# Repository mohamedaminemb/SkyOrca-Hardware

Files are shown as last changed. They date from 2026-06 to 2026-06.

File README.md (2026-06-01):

# SkyOrca — Quadcopter Drone Hardware

<p align="center">
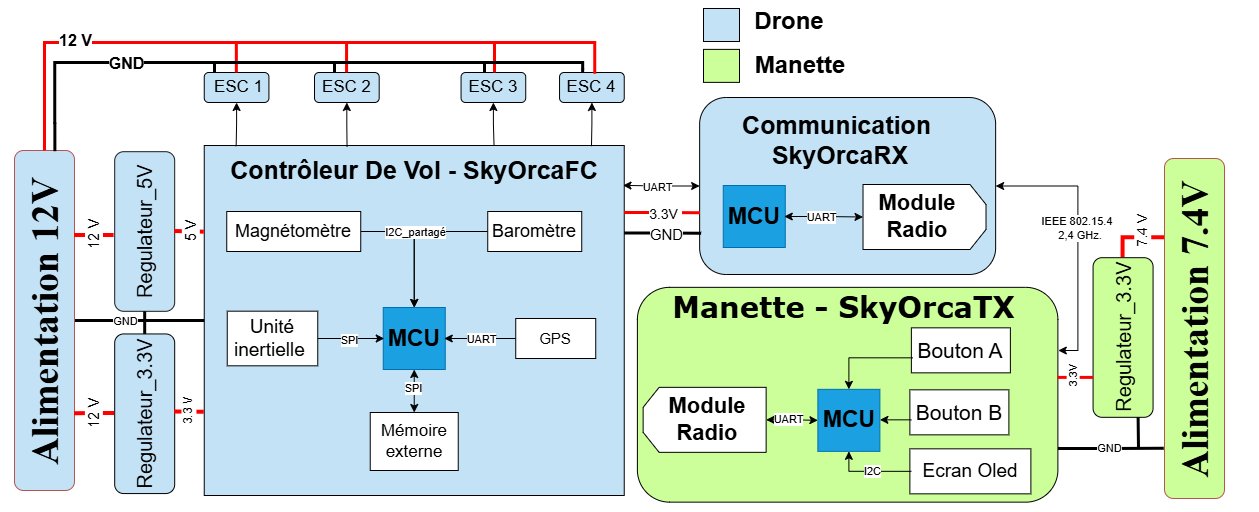
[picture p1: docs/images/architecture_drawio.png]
SkyOrca System Architecture
  
</p>

<p align="center">
  
  
  
  
  
</p>

> **SkyOrca** is a fully custom quadcopter drone system designed from scratch at ENSI (Tunisia), in partnership with [LAB619 Engineering & Consulting Services](https://lab619.tn). This repository contains the complete hardware design — schematics, PCB layouts, Gerber files, and BOMs — for all three boards.

---

## System Overview

SkyOrca is built around three custom PCBs that together form a complete drone flight & control chain:

| Board | Role | MCU | Dimensions |
|---|---|-----|---|
| **SkyOrcaFC** | Flight Controller | STM32F405RGTx @ 168 MHz | 60 × 50 mm |
| **SkyOrcaTX** | Remote Controller (Transmitter) | ATmega328P-P @ 8 MHz | 50 × 35 mm |
| **SkyOrcaRX** | Communication Module (Receiver) | ATmega2560-16A @ 8 MHz | 30 × 25 mm |

---

## Repository Structure

```
SkyOrca-Hardware/
├── hardware/
│   ├── SkyOrcaFC/              # Flight Controller Board
│   │   ├── kicad/              # KiCad project files (.kicad_pro, .kicad_sch, .kicad_pcb)
│   │   ├── gerbers/            # Production Gerber files + drill files
│   │   └── bom/                # Bill of Materials (CSV + interactive iBOM)
│   ├── SkyOrcaTX/              # Remote Controller Board
│   │   ├── kicad/
│   │   ├── gerbers/
│   │   └── bom/
│   └── SkyOrcaRX/              # Receiver Module
│       ├── kicad/
│       └── bom/
├── docs/
│   ├── images/                 # architecture_drawio.png + board renders
│   ├── SkyOrcaFC.md
│   ├── SkyOrcaTX.md
│   ├── SkyOrcaRX.md
│   └── design_decisions.md
├── .gitignore
├── LICENSE
└── README.md
```

---

## Board Details

### SkyOrcaFC — Flight Controller

The brain of the drone. Reads all sensors, runs stabilization algorithms, and drives the four ESCs.

**Key components:**
- **MCU:** STM32F405RGTx — Cortex-M4F @ 168 MHz, hardware FPU (quaternion math, sensor fusion at 400 Hz)
- **IMU:** MPU-6000 — SPI @ 20 MHz, DMA-triggered via EXTI interrupt, 400 Hz control loop
- **Barometer:** MS5611-01BA — 10 cm altitude resolution, I²C shared bus
- **Magnetometer:** HMC5883L — I²C shared bus
- **GPS:** u-blox MAX-M10S — multi-constellation (GPS/GLONASS/Galileo/BeiDou), UART
- **Flash:** W25Q128JVS — 128 Mbit, SPI @ 133 MHz, flight data logging
- **Power:** Dual TPS5430DDA buck converters (12V→5V and 12V→3.3V)
- **PCB:** 4-layer, 60×50 mm (rev 2), manufactured by JLCPCB

> **PCB revisions:** The first revision (50×50 mm) was redesigned due to GPS/DC-DC proximity and thermal density issues. See [`docs/SkyOrcaFC.md`](docs/SkyOrcaFC.md) for the full analysis.

---

### SkyOrcaTX — Remote Controller

Hand-held transmitter reading pilot inputs and displaying telemetry.

**Key components:**
- **MCU:** ATmega328P-P @ 8 MHz (DIP-28)
- **Radio:** XBee 802.15.4 module — bidirectional, up to 1.6 km range, UART interface
- **Inputs:** 2× analog joysticks (4-axis), 2 buttons
- **Display:** OLED (I²C) — battery level, altitude, RSSI
- **Power:** TPS5430DDA buck converter (7.4V→3.3V)
- **PCB:** 4-layer, 50×35 mm

---

### SkyOrcaRX — Receiver Module

On-board radio bridge between the XBee link and the Flight Controller.

**Key components:**
- **MCU:** ATmega2560-16A @ 8 MHz — 4 hardware UARTs (radio / FC link / debug / spare)
- **Radio:** XBee 802.15.4 module
- **Interface to FC:** UART2 → `IBUS_RX_MCU` on SkyOrcaFC
- **Power:** 3.3V supplied directly by SkyOrcaFC
- **PCB:** 4-layer, 30×25 mm

---

## Inter-Board Communication

| Link | Signal | Protocol |
|---|---|---|
| TX → RX (commands) | XBee RF 2.4 GHz | IEEE 802.15.4 |
| RX → FC (commands) | `UART2` → `IBUS_RX_MCU` | UART |
| FC → TX (telemetry) | `MSP_TX_MCU` → XBee → `RXD_MCU` | UART + XBee RF |
| FC → ESC 1–4 | `Signal_ESC1–4` | PWM |

All three boards share a **3.3V logic level**, eliminating any need for level shifters between STM32 and ATmega devices.

---

## Getting Started

### Prerequisites

- [KiCad 9.0.x](https://www.kicad.org/download/) to open and edit the project files

### Opening a Project

```bash
git clone https://github.com/mohamedaminemb/SkyOrca-Hardware.git
cd SkyOrca-Hardware

# Open the Flight Controller in KiCad
kicad hardware/SkyOrcaFC/kicad/flightcontrolerPCB.kicad_pro
```

### Ordering PCBs (SkyOrcaFC)

Upload `hardware/SkyOrcaFC/gerbers/gerbers_production.zip` to [JLCPCB](https://jlcpcb.com):

| Setting | Value |
|---|---|
| Layers | **4** |
| PCB thickness | **1.6 mm** |
| Surface finish | **HASL (lead-free)** or **ENIG** |
| Min trace/space | **0.15 / 0.15 mm** |

---

## Design Philosophy

This project follows a **hardware/software co-design** methodology. Every component choice is directly motivated by firmware constraints. See [`docs/design_decisions.md`](docs/design_decisions.md) for the full rationale.

---

## Project Context

SkyOrca is a design and development project (PCD) at **ENSI** (École Nationale des Sciences de l'Informatique, Tunisia), developed in the context of Tunisia's first civil drone legislation (Finance Law 2026, Article 135), in collaboration with **LAB619 Engineering & Consulting Services**.

**Team:** Mohamed Amine Embarki · Hamza Soltani  
**Supervisors:** Mme. Chadha Jerad · M. Jawher Mansour (LAB619)  
**Tools:** KiCad 9.0.4 · JLCPCB

---

## License

Hardware designs are released under the **CERN Open Hardware Licence v2 – Strongly Reciprocal (CERN-OHL-S)**.  
See [`LICENSE`](LICENSE) for details.

---

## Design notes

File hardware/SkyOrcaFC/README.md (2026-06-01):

# SkyOrcaFC — Flight Controller Board

> Full design documentation: [`docs/SkyOrcaFC.md`](../../docs/SkyOrcaFC.md)

## Quick Specs

| Parameter | Value |
|---|---|
| MCU | STM32F405RGTx |
| Dimensions | 60 × 50 mm |
| Layers | 4 |
| Power input | 12V (LiPo 3S) |
| Control loop | 400 Hz (DMA, IMU interrupt) |
| Revision | 2 (production) |

---

## 3D Views

| Front | Back |
|---|---|
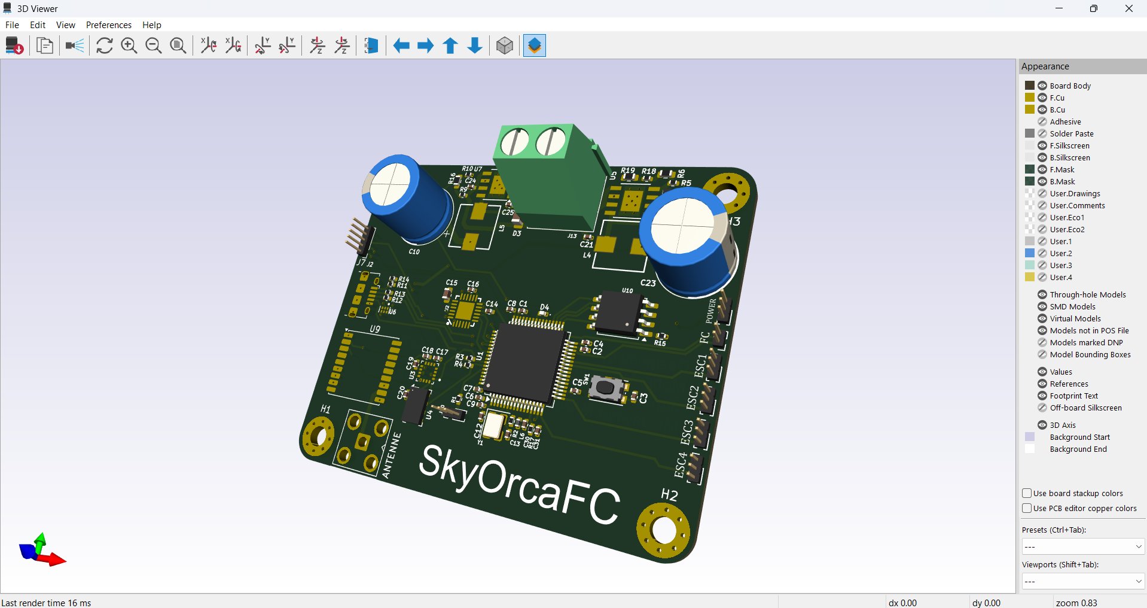
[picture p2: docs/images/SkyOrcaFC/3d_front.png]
3D Front
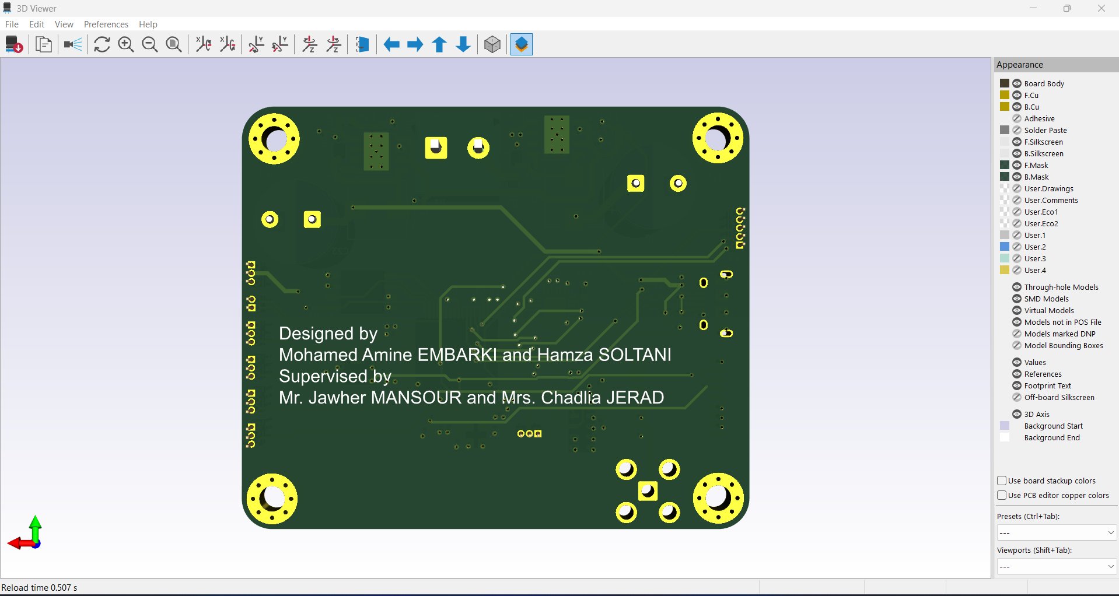
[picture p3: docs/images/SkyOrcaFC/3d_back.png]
3D Back
|  |  |

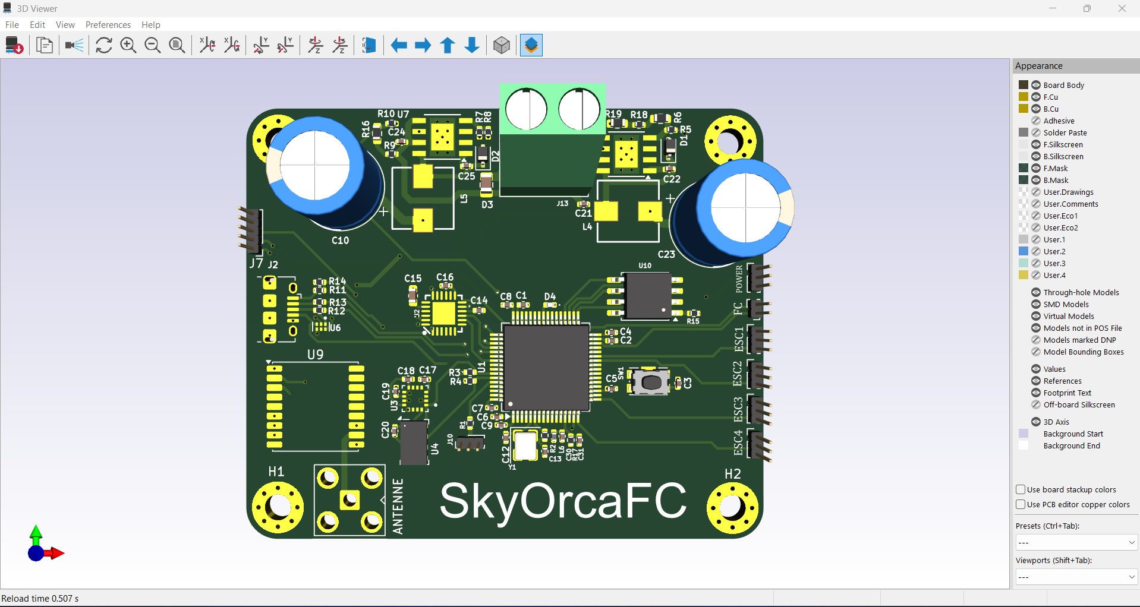
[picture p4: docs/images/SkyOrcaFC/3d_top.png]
3D Top


---

## PCB Layers

| Layer | Preview |
|---|---|
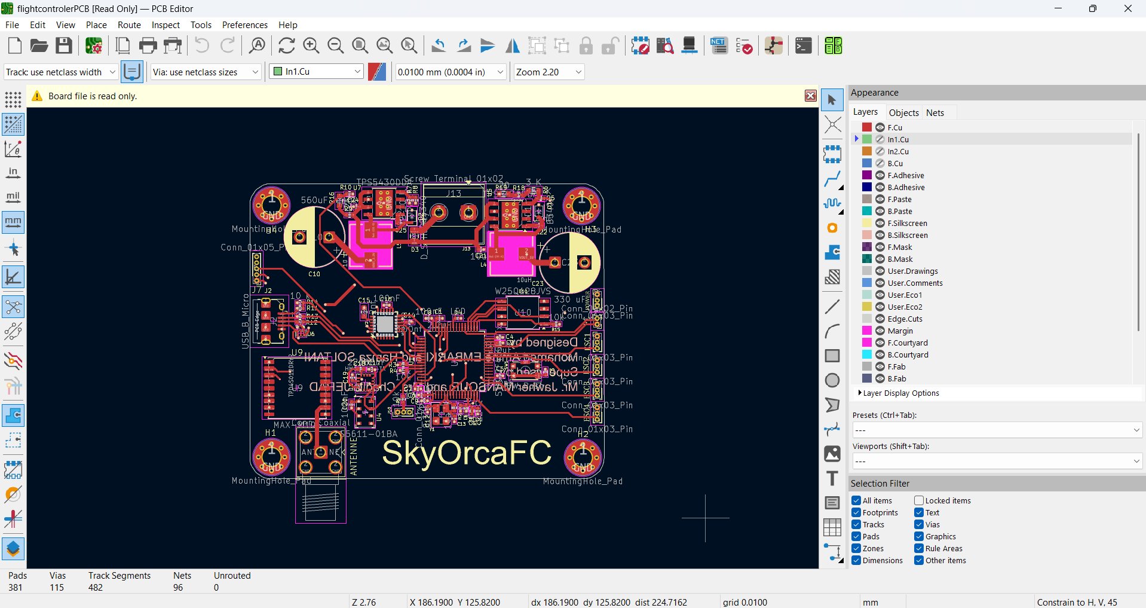
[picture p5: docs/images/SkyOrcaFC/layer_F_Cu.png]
F.Cu
| **F.Cu** — Front copper (signal + components) |  |
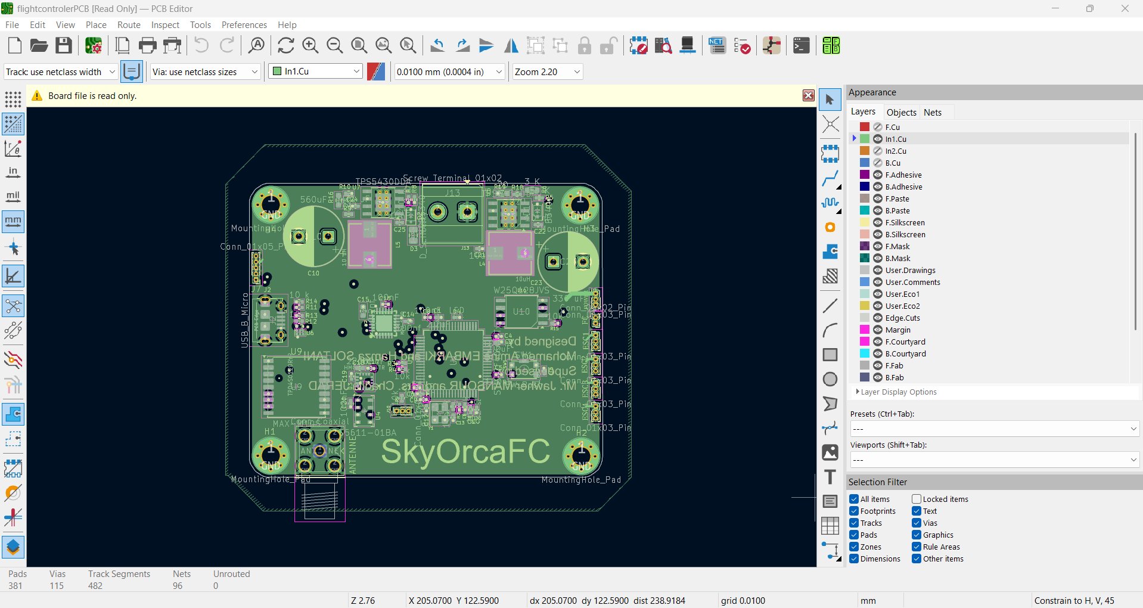
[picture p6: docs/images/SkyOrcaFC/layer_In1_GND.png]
In1 GND
| **In1.Cu** — Ground plane |  |
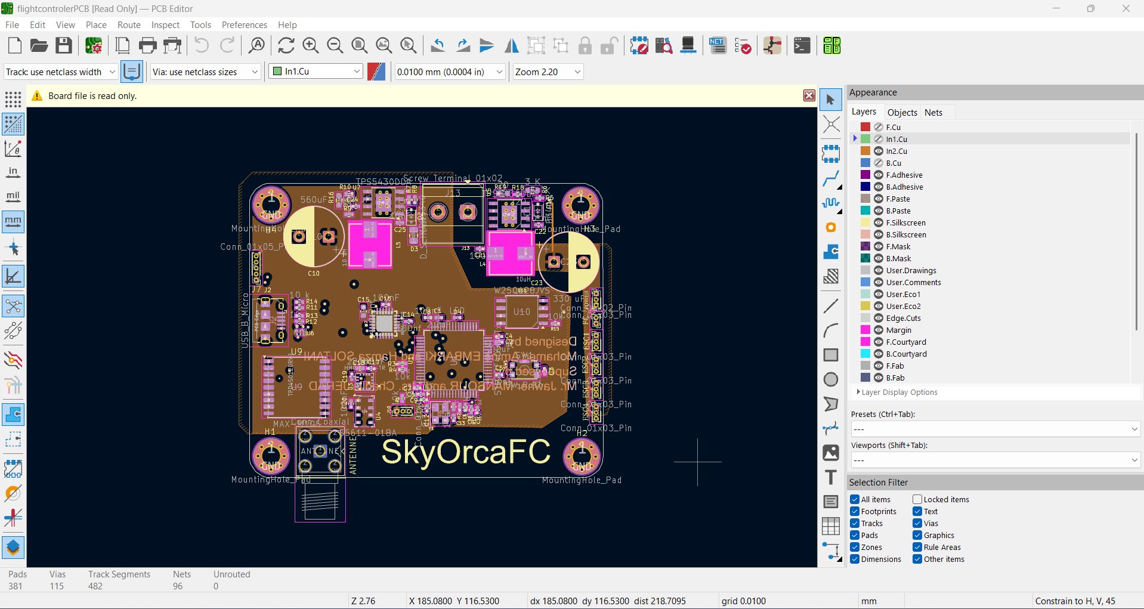
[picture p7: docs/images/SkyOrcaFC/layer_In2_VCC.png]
In2 VCC
| **In2.Cu** — Power plane (3.3V / 5V) |  |
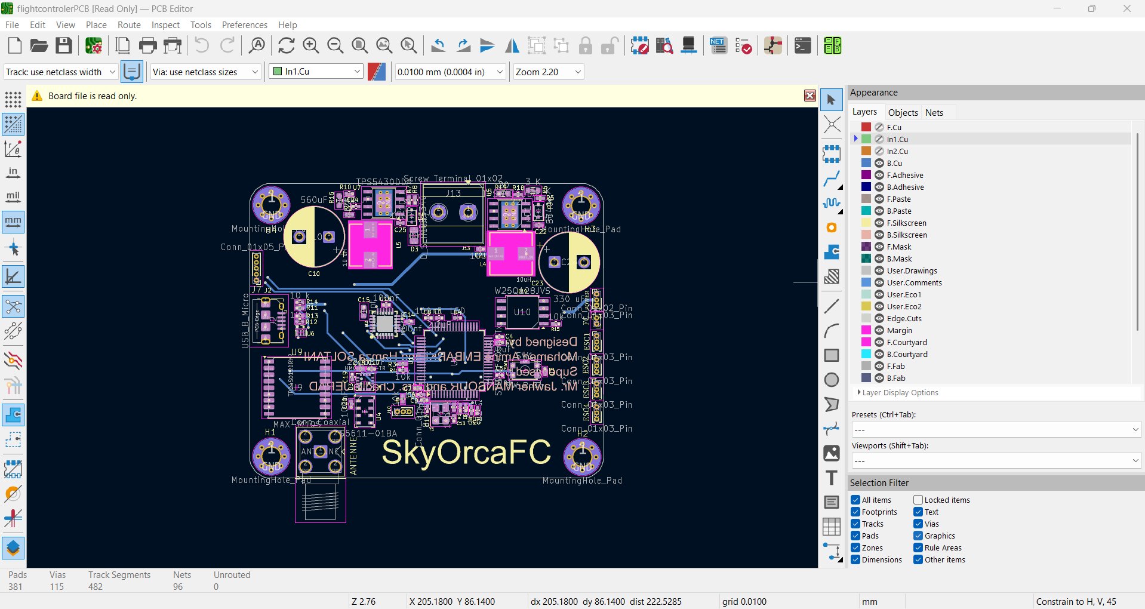
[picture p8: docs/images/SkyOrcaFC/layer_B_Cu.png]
B.Cu
| **B.Cu** — Back copper (signal) |  |

---

## Contents

```
SkyOrcaFC/
├── kicad/
│   ├── flightcontrolerPCB.kicad_sch    # Schematic
│   ├── flightcontrolerPCB.kicad_pcb    # PCB layout (4-layer, 60×50 mm)
│   └── schematic.pdf                   # Schematic PDF
└── docs/images/SkyOrcaFC/              # 3D renders + layer screenshots
```

## Ordering
## Ordering

Upload the Gerber zip to [JLCPCB](https://jlcpcb.com):

| Setting | Value |
|---|---|
| Layers | **4** |
| PCB thickness | **1.6 mm** |
| Surface finish | **HASL (lead-free)** or **ENIG** |
| Min trace/space | **0.15 / 0.15 mm** |

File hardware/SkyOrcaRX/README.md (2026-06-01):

# SkyOrcaRX — Receiver / Communication Module

> Full design documentation: [`docs/SkyOrcaRX.md`](../../docs/SkyOrcaRX.md)

## Contents

```
SkyOrcaRX/
├── kicad/
│   ├── SkyOrcaRX.kicad_pro
│   ├── SkyOrcaRX.kicad_sch
│   ├── SkyOrcaRX.kicad_pcb
│   └── schematic.pdf
└── bom/
    (BOM to be exported from KiCad project)
```

## Quick Specs

| Parameter | Value |
|---|---|
| MCU | ATmega2560-16A @ 8 MHz |
| Dimensions | 30 × 25 mm |
| Layers | 4 |
| Power input | 3.3V from SkyOrcaFC |
| Radio | XBee 802.15.4 |
| UARTs | 4 (radio / FC link / debug / spare) |
| Revision | 1 |

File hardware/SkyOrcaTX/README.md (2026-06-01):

# SkyOrcaTX — Remote Controller Board

> Full design documentation: [`docs/SkyOrcaTX.md`](../../docs/SkyOrcaTX.md)

## Contents

```
SkyOrcaTX/
├── kicad/
│   ├── SkyOrcaTX.kicad_pro
│   ├── SkyOrcaTX.kicad_sch
│   ├── SkyOrcaTX.kicad_pcb
│   └── schematic.pdf
└── bom/
    └── ibom.html                       # Interactive BOM (open in browser)
```

## Quick Specs

| Parameter | Value |
|---|---|
| MCU | ATmega328P-P @ 8 MHz |
| Dimensions | 50 × 35 mm |
| Layers | 4 |
| Power input | 7.4V (LiPo 2S) |
| Radio | XBee 802.15.4 (up to 1.6 km) |
| Revision | 1 |

## Ordering

No Gerber zip is included in this release — contact the project team or generate from the KiCad project. Use the same JLCPCB 4-layer settings as SkyOrcaFC.

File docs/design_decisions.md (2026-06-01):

# Design Decisions & Rationale

This document captures the key cross-board design decisions made during the SkyOrca hardware development, explaining *why* each choice was made rather than just *what* was chosen.

---

## 1. Hardware/Software Co-Design Approach

SkyOrca was developed using a **HW/SW co-design** methodology — hardware and software decisions were made jointly and iteratively, rather than sequentially.

This was essential because:

- The IMU interface (SPI vs I²C) directly determines whether the firmware can achieve a 400 Hz control loop via DMA, or must fall back to polling at lower rates.
- The number of hardware UARTs on the SkyOrcaRX MCU determines whether telemetry can be handled without software multiplexing — which would introduce non-deterministic latency.
- PCB trace lengths and layer assignment affect which sensors can share buses, directly constraining firmware architecture.

Every component table in this repository reflects this joint reasoning.

---

## 2. Why 4-Layer PCBs for All Three Boards

Even the smaller SkyOrcaTX and SkyOrcaRX boards were routed on 4 layers, despite lower component density. The reasons:

- **Continuous ground plane (In1.Cu)** — essential for XBee RF reliability. A fragmented ground plane raises return path impedance and creates unintentional loop antennas, degrading link margin.
- **Dedicated power plane (In2.Cu)** — isolates DC-DC switching noise from signal layers.
- **Signal integrity** — high-frequency SPI signals (up to 20 MHz on the IMU) require a reference plane directly beneath the trace to maintain controlled impedance and minimize crosstalk.

2-layer boards were evaluated and rejected: the fragmented ground plane would have created inductive coupling between the 8 kHz ESC PWM signals and the SPI bus serving the IMU.

---

## 3. SkyOrcaFC Revision 1 → Revision 2

The first PCB revision (50×50 mm) was rejected after layout review with LAB619. Two structural problems were found:

**Problem A — GPS near DC-DC converters**

The TPS5430 converters switch at approximately 500 kHz. Their harmonics extend into the tens of MHz range, and the common-mode noise they inject into the power plane can degrade the GPS receiver sensitivity (signal level ≈ −130 dBm). In revision 1, the GPS connector was less than 5 mm from the converter components with no keepout zone around the antenna.

Fix in revision 2:
- GPS block moved to the opposite corner from the DC-DC island (> 15 mm separation).
- 10 mm RF keepout zone added around the GPS antenna footprint — no copper pours allowed inside.

**Problem B — Thermal density around IMU**

Both converters were placed close to the MPU-6000. A temperature rise of even +10 °C on the IMU introduces a gyroscope bias that is not compensated by the complementary filter and directly degrades attitude estimation accuracy.

Fix in revision 2:
- DC-DC converters grouped in a dedicated thermal corner with their passives (inductor, diode, bulk caps).
- STM32F405 placed at the board center, minimising maximum trace length to all peripherals.

The 20% area increase (50×50 → 60×50 mm) was accepted as fully justified by the elimination of these two failure modes.

---

## 4. Logic Level Unification at 3.3V

All three boards operate at **3.3V logic** — the STM32F405 is natively 3.3V, and the ATmega328P / ATmega2560 are powered at 3.3V as well (within their operating range at 8 MHz).

This eliminates the need for any level shifters on the inter-board UART links (`UART2` between SkyOrcaRX and SkyOrcaFC, `MSP_TX_MCU` telemetry path), reducing component count and removing a potential failure point.

---

## 5. XBee Over nRF24L01 / LoRa

| Criterion | nRF24L01 | LoRa SX1276 | XBee 802.15.4 |
|---|---|---|---|
| MCU interface | SPI | SPI / UART | UART |
| Bidirectional | Yes | Partial | Native |
| Firmware complexity | High | High | Low |
| Range | ~100 m | Several km | ~1.6 km |
| Telemetry support | No | Partial | Yes |

The nRF24L01 was rejected because it requires the firmware to implement the full packet management layer (auto-ACK, pipe addressing, retransmit logic) over SPI — adding significant firmware complexity on a board (SkyOrcaRX) that has no FPU and limited flash.

LoRa was rejected because its long-range capability introduces latency (Time-on-Air) incompatible with real-time control link requirements at typical drone operating distances (< 500 m).

XBee operates over IEEE 802.15.4 and presents a simple UART interface to the MCU — the module handles the entire MAC layer internally.

---

## 6. Flash Memory for Flight Data Logging

The W25Q128JVS (128 Mbit NOR Flash) is connected on a **dedicated SPI2 bus** on the SkyOrcaFC, separate from the IMU's SPI3 bus. This ensures that asynchronous write operations to the flash (triggered at a lower rate than the 400 Hz control loop) never create bus contention that could delay an IMU read.

Quad-SPI capability (133 MHz) allows burst writes during low-activity phases without blocking the control loop.

---

## 7. Partnership with LAB619

The collaboration with LAB619 Engineering & Consulting Services was not optional — it was a technical necessity for two reasons:

1. **4-layer PCB manufacturing** — No Tunisian PCB fabricator offers 4-layer boards at academic project scale. All boards were manufactured by JLCPCB (Shenzhen) and imported through LAB619's registered commercial entity.
2. **Component sourcing** — The Tunisian electronics distribution market is limited to basic passives and entry-level microcontrollers. Every active component in SkyOrca (STM32F405, MPU-6000, MS5611, MAX-M10S, XBee, TPS5430) was unavailable locally and required international procurement.

LAB619 also contributed PCB design review (DRC validation, signal integrity analysis) and access to professional assembly equipment (reflow station, oscilloscopes, logic analyzers).

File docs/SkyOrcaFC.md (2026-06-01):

# SkyOrcaFC — Flight Controller Board

## Overview

The SkyOrcaFC is the central board of the SkyOrca drone. It is responsible for reading all onboard sensors, running the attitude estimation and stabilization algorithms, and generating the PWM commands sent to the four ESCs.

- **MCU:** STM32F405RGTx (Cortex-M4F @ 168 MHz, hardware FPU)
- **PCB:** 4 layers, 60 × 50 mm (revision 2)
- **Power input:** 12V from main LiPo battery

---

## Component Selection

### Microcontroller — STM32F405RGTx

| Family | Core | FPU | Freq | SPI buses |
|---|---|-----|---|---|
| STM32F1 | Cortex-M3 | ✗ | 72 MHz | 2 |
| STM32F3 | Cortex-M4 | ✓ | 144 MHz | 3 |
| **STM32F405** | **Cortex-M4F** | **✓** | **168 MHz** | **3** |
| STM32F7 | Cortex-M7 | ✓ | 280 MHz | 6 |

The F405 was chosen for its hardware FPU (quaternion math and complementary filter at 400 Hz), two independent SPI buses (one dedicated to the IMU, one to flash memory), and advanced timers for high-frequency PWM generation on ESC outputs.

### IMU — MPU-6000

The MPU-6000 was preferred over the MPU-6050 (I²C only) due to its SPI interface running up to 20 MHz, combined with a dedicated hardware interrupt line (`GYRO_1_EXTI`). This allows the firmware to trigger DMA reads directly from the EXTI interrupt, achieving a deterministic 400 Hz control loop without any polling.

Gyroscope noise floor: 0.005 °/s/√Hz.

### Barometer — MS5611-01BA

10 cm altitude resolution, 1 µA standby current, I²C interface shared with the magnetometer on `I2C1`. The MS5611 was selected over the BMP280 (≈1 m resolution) because altitude-hold at centimeter precision is a key requirement.

### Magnetometer — HMC5883L

I²C interface, shared on `I2C1` with the barometer. The QMC5883L was rejected due to poor EMI immunity. A migration path to the HMC5983 (adds SPI) is planned for revision 3.

### GPS — u-blox MAX-M10S

Multi-constellation (GPS / GLONASS / Galileo / BeiDou), −167 dBm sensitivity, 11 mA active current. Connected to the STM32 via UART. The ultra-compact LCC package makes it well suited for this form factor.

### Flash — W25Q128JVS

128 Mbit serial NOR Flash, SPI up to 133 MHz, quad-SPI capable. Used for flight data logging and calibration parameter storage. The dedicated `SPI2` bus ensures no contention with the IMU on `SPI3`.

### Power — TPS5430DDA (×2)

| Stage | Input | Output | Load |
|---|---|---|---|
| U5 | 12V | 5V | ESCs, 5V peripherals |
| U7 | 12V | 3.3V | STM32, sensors, GPS, flash |

Both converters use a feedback divider sized for exact output voltage, a 10 µH shielded inductor, Schottky diode, and bulk output capacitance. The DC-DC blocks are placed in a thermal island in one corner of the PCB, isolated from sensor components.

---

## Schematic Notes

The schematic is split across two sheets.

**Sheet 1 — MCU & peripherals:**
- `SPI3` → IMU (MOSI/MISO/SCK + `GYRO_1_CS`)
- `SPI2` → Flash W25Q128JVS (`CS_FLASH`)
- `I2C1` → Magnetometer + Barometer (shared bus, 4.7 kΩ pull-ups)
- `GYRO_1_EXTI` → IMU INT pin → STM32 EXTI for DMA trigger
- `UART` → GPS (`GPS_TX`, `GPS_RX`)
- `UART` → SkyOrcaRX (`IBUS_RX_MCU`, `MSP_TX_MCU`)
- `TIM` outputs → `Signal_ESC1` … `Signal_ESC4` (dedicated PWM timer channels)
- USB Micro-B with ESD protection, 22 Ω series resistors on D+/D−
- SWD connector (SWDIO / SWDCLK / NRST)

**Sheet 2 — Sensors, power, flash:**
- Each sensor has a dedicated 100 nF decoupling cap placed within 2 mm of the VDD pin.
- VDDA separated from VDDD by a 39 nH ferrite bead + 4.7 nF + 100 nF.
- Battery voltage divider → ADC pin (`Niveaux_Battrie`).

---

## PCB Revisions

### Revision 1 — 50 × 50 mm

Initial compact layout. Two critical problems were identified:

1. **GPS block adjacent to DC-DC converters** — Switching harmonics (fsw ≈ 500 kHz, harmonics up to tens of MHz) at risk of coupling into the GPS antenna path. GPS signal level is approximately −130 dBm; any added noise is significant.
2. **Thermal density too high** — Both TPS5430 converters were within thermal range of the IMU. A +10 °C temperature rise on the MPU-6000 introduces a measurable gyroscope bias offset, degrading attitude estimation.

### Revision 2 — 60 × 50 mm ✅ (production)

20% area increase resolves both issues:

| Criterion | Rev 1 | Rev 2 |
|---|---|---|
| GPS–DC-DC distance | < 5 mm | > 15 mm |
| RF keepout zone | Absent | 10 mm around GPS |
| Thermal isolation | None | DC-DC in dedicated corner |
| SPI trace length | Constrained | Optimised |
| Connector accessibility | Difficult | Good |

The STM32F405 is centred on the board to minimise maximum trace length to all peripherals.

---

## Routing Rules (JLCPCB 4-layer)

| Parameter | Value |
|---|---|
| Signal trace width | 0.2 mm |
| Power trace width | 0.8–1.5 mm |
| ESC PWM trace | 0.5 mm |
| Minimum clearance | 0.15 mm |
| Via diameter | 0.6 mm (0.3 mm drill) |
| GPS antenna keepout | 10 mm |
| Decoupling placement | < 2 mm from VDD pin |
| GPS antenna trace | < 1/12 wavelength (9 mm) |

Layer stackup: `F.Cu (signal)` / `In1.Cu (GND)` / `In2.Cu (PWR)` / `B.Cu (signal)`

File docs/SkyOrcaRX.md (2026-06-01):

# SkyOrcaRX — Receiver / Communication Module

## Overview

The SkyOrcaRX sits on the drone between the XBee radio link and the SkyOrcaFC flight controller. It decodes incoming command frames from the remote controller and forwards them to the FC over UART, while also relaying telemetry data from the FC back to the transmitter.

- **MCU:** ATmega2560-16A @ 8 MHz
- **Radio:** XBee 802.15.4
- **PCB:** 4 layers, 30 × 25 mm
- **Power:** 3.3V supplied by SkyOrcaFC (no on-board regulator)

---

## Component Selection

### Microcontroller — ATmega2560-16A

The ATmega2560 was chosen specifically for its **4 independent hardware UART channels**:

| UART | Assignment |
|---|---|
| UART3 | XBee radio (receive commands, transmit telemetry) |
| UART2 | SkyOrcaFC link — `IBUS_RX_MCU` signal |
| UART0 | Debug / serial monitor |
| UART1 | Reserved for future extensions |

The ATmega328P (1 UART) and STM32F103 (3 UARTs) were ruled out due to insufficient UART count without multiplexing, which would introduce latency and firmware complexity in a time-critical link.

---

## Schematic Notes

Single-sheet design. Key circuits:

- **Quartz:** 8 MHz with 22 pF load capacitors
- **UART3 XBee:** dual 10-pin connectors (`UART3_XBEE1`, `UART3_XBEE2`)
- **UART2:** 2-pin connector → `IBUS_RX_MCU` on SkyOrcaFC
- **UART0:** 3-pin debug connector
- **ICSP/SPI:** MOSI / MISO / SCK / RESET for ATmega2560 programming
- **Extensions:** J3 — GPIO1, GPIO2, GPIO3/PWM; I²C connector (SDA/SCL)
- **Power:** `POWER1` 3-pin connector — 3.3V input from SkyOrcaFC; no local regulator
- **Reset:** SW1 with 10 kΩ pull-up
- **Decoupling:** 100 nF on each VCC pin; 22 pF on AREF

---

## Data Flow

```
SkyOrcaTX (XBee TX)
       │  RF 2.4 GHz
       ▼
SkyOrcaRX — XBee RX
       │  UART3 receive
       ▼
ATmega2560 — decode & forward
       │  UART2 → IBUS_RX_MCU
       ▼
SkyOrcaFC — flight control loop

◄──────────────────────────────
  Telemetry path (reverse):
  SkyOrcaFC MSP_TX_MCU → UART2 → ATmega2560 → UART3 → XBee TX → SkyOrcaTX
```

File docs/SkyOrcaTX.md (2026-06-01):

# SkyOrcaTX — Remote Controller Board

## Overview

The SkyOrcaTX is the hand-held remote controller. It reads pilot inputs from two analog joysticks and two buttons, transmits commands wirelessly to the drone via XBee, and displays telemetry data received back from the drone on an OLED screen.

- **MCU:** ATmega328P-P @ 8 MHz (DIP-28)
- **Radio:** XBee 802.15.4
- **PCB:** 4 layers, 50 × 35 mm
- **Power input:** 7.4V LiPo (2S)

---

## Component Selection

### Microcontroller — ATmega328P-P

The ATmega328P was chosen for its 6 ADC input channels (reading 4 joystick axes on PC0–PC3 + 2 spare), 1 hardware UART (XBee communication), DIP-28 package for prototyping ease, and low cost. The ATtiny85 was ruled out due to insufficient UART and ADC count; the ATmega2560 was overkill for this role.

Clocked at 8 MHz by an external crystal with 20 pF load capacitors.

### Radio — XBee 802.15.4

XBee was selected over nRF24L01 and LoRa SX1276 for three reasons:
1. **UART-native interface** — no low-level SPI protocol management in firmware; the module handles framing, addressing, and retransmission internally.
2. **Native bidirectional link** — the same module handles both TX (commands) and RX (telemetry) without additional configuration.
3. **Proven RF robustness** — the 802.15.4 PHY layer provides reliable links in RF-noisy environments typical of outdoor drone operation.

Range: up to 1.6 km line-of-sight.

Two XBee footprints (10-pin connectors) are provided for redundancy / future upgrade path.

### Power — TPS5430DDA (7.4V → 3.3V)

Same converter family as the SkyOrcaFC for supply chain simplicity. Feedback divider: R7 (10 kΩ) / R8 (5.9 kΩ).

---

## Schematic Notes

**Sheet 1 — ATmega328P and interfaces:**
- `VRXG`, `VRYG` → left joystick X/Y on `ADC0`, `ADC1`
- `VRXD`, `VRYD` → right joystick X/Y on `ADC2`, `ADC3`
- `RXD_MCU_xbee` / `TXD_MCU_xbee` → XBee UART
- I²C connector available for OLED display (`SSD1306` or equivalent)
- ICSP/SWD connector for in-circuit programming
- Reset button with 10 kΩ pull-up and 100 nF debounce capacitor
- 100 nF decoupling on VCC and AVCC pins

**Sheet 2 — Power:**
- TPS5430DDA in 7.4V→3.3V configuration
- 10 µH inductor + Schottky diode + 560 µF + 4.7 µF bulk output capacitors
- Four M3 mounting holes for enclosure integration

---

## Joystick Mapping

| Signal | ATmega Pin | Axis |
|---|---|---|
| VRXG | PC0 / ADC0 | Left joystick — X (Roll) |
| VRYG | PC1 / ADC1 | Left joystick — Y (Throttle) |
| VRXD | PC2 / ADC2 | Right joystick — X (Yaw) |
| VRYD | PC3 / ADC3 | Right joystick — Y (Pitch) |

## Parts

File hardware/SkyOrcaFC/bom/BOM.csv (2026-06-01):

Reference | Qty | Value | DNP | Exclude from BOM | Exclude from Board | Footprint | Datasheet
C1,C2 | 2 | 2.2uF |  |  |  | Capacitor_SMD:C_0805_2012Metric | ~
C3 | 1 | 0.1 uF |  |  |  | Capacitor_SMD:C_0805_2012Metric | ~
C4,C27 | 2 | 100 nF |  |  |  | Capacitor_SMD:C_0805_2012Metric | ~
C5,C6,C7,C8,C16,C17,C20,C31 | 8 | 100nF |  |  |  | Capacitor_SMD:C_0805_2012Metric | ~
C9 | 1 | 4.7nF |  |  |  | Capacitor_SMD:C_0805_2012Metric | ~
C12,C13 | 2 | 10pF |  |  |  | Capacitor_SMD:C_0805_2012Metric | ~
C14 | 1 | 100nf |  |  |  | Capacitor_SMD:C_0805_2012Metric | ~
C15 | 1 | 2.2nf |  |  |  | Capacitor_SMD:C_0805_2012Metric | ~
C18 | 1 | 220nF |  |  |  | Capacitor_SMD:C_0805_2012Metric | ~
C19 | 1 | 4.7uF |  |  |  | Capacitor_SMD:C_0805_2012Metric | ~
C21 | 1 | 10uF |  |  |  | Capacitor_SMD:C_0805_2012Metric | ~
C22 | 1 | 10 nF |  |  |  | Capacitor_SMD:C_0805_2012Metric | ~
C23 | 1 | 220 uF |  |  |  | Capacitor_SMD:CP_Elec_10x10.5 | ~
C24 | 1 | 4.7 uF |  |  |  | Capacitor_SMD:C_0805_2012Metric | ~
C25 | 1 | 10nF |  |  |  | Capacitor_SMD:C_0805_2012Metric | ~
C26 | 1 | 100 uF |  |  |  | Capacitor_SMD:C_0805_2012Metric | ~
C28 | 1 | 150 pF |  |  |  | Capacitor_SMD:C_0805_2012Metric | ~
C29 | 1 | 1500 pF |  |  |  | Capacitor_SMD:C_0805_2012Metric | ~
C30 | 1 | 1uF |  |  |  | Capacitor_SMD:C_0805_2012Metric | ~
D1 | 1 | B340A |  |  |  | Diode_SMD:D_SOD-123 | ~
D2 | 1 | MRBS340 |  |  |  | Diode_SMD:D_SOD-123 | ~
D3 | 1 | D_Schottky |  |  |  | Capacitor_SMD:C_0805_2012Metric | ~
D4 | 1 | LED |  |  |  | LED_SMD:LED_0402_1005Metric | ~
H1,H2,H3,H4 | 4 | MountingHole_Pad |  |  |  | MountingHole:MountingHole_3mm_Pad_Via | ~
J1 | 1 | Conn_Coaxial |  |  |  | Connector_Coaxial:SMA_Amphenol_901-143_Horizontal | ~
J2 | 1 | USB_B_Micro |  |  |  | Connector_USB:USB_Micro-B_Amphenol_10118194_Horizontal | ~
J3,J4,J5,J6,J9 | 5 | Conn_01x03_Pin |  |  |  | Connector_PinHeader_1.00mm:PinHeader_1x03_P1.00mm_Horizontal | ~
J7 | 1 | Conn_01x05_Pin |  |  |  | Connector_PinHeader_1.00mm:PinHeader_1x05_P1.00mm_Horizontal | ~
J8 | 1 | Conn_01x02_Pin |  |  |  | Connector_PinHeader_1.00mm:PinHeader_1x02_P1.00mm_Horizontal | ~
J10 | 1 | Conn_01x06_Pin |  |  |  | Connector_PinHeader_1.00mm:PinHeader_1x06_P1.00mm_Horizontal | ~
J13 | 1 | Screw_Terminal_01x02 |  |  |  | TerminalBlock_Phoenix:TerminalBlock_Phoenix_MKDS-1,5-2_1x02_P5.00mm_Horizontal | ~
L2,L3 | 2 | 2.2kH |  |  |  | Inductor_SMD:L_0805_2012Metric | ~
L4,L5 | 2 | 15 uH |  |  |  | Inductor_SMD:L_7.3x7.3_H4.5 | ~
L6 | 1 | 39nH |  |  |  | Inductor_SMD:L_0805_2012Metric | ~
R1,R3,R4,R10,R15 | 5 | 10k |  |  |  | Resistor_SMD:R_0805_2012Metric | ~
R2 | 1 | 2 k |  |  |  | Resistor_SMD:R_0805_2012Metric | ~
R5,R7 | 2 | 10 K |  |  |  | Resistor_SMD:R_0805_2012Metric | ~
R6 | 1 | 3.24 K |  |  |  | Resistor_SMD:R_0805_2012Metric | ~
R8 | 1 | 5.9 K |  |  |  | Resistor_SMD:R_0805_2012Metric | ~
R9 | 1 | 549 |  |  |  | Resistor_SMD:R_0805_2012Metric | ~
R11,R14 | 2 | 10 k |  |  |  | Resistor_SMD:R_0805_2012Metric | ~
R12,R13 | 2 | 22 |  |  |  | Resistor_SMD:R_0805_2012Metric | ~
R16 | 1 | 26k |  |  |  | Resistor_SMD:R_0805_2012Metric | ~
R17 | 1 | R |  |  |  | Resistor_SMD:R_0805_2012Metric | ~
SW1 | 1 | SW_Push |  |  |  | Button_Switch_THT:SW_Tactile_SPST_Angled_PTS645Vx31-2LFS | ~
SW2 | 1 | SW_SPDT |  |  |  | Button_Switch_THT:SW_Slide-03_Wuerth-WS-SLTV_10x2.5x6.4_P2.54mm | ~
U1 | 1 | STM32F405RGTx |  |  |  | Package_QFP:LQFP-64_10x10mm_P0.5mm | https://www.st.com/resource/en/datasheet/stm32f405rg.pdf
U2 | 1 | MPU-6000 |  |  |  | sky:QFN-24-EP | https://invensense.tdk.com/wp-content/uploads/2015/02/MPU-6000-Datasheet1.pdf
U3 | 1 | HMC5883L-TR |  |  |  | sky:XDCR_HMC5883L-TR
U4 | 1 | MS5611-01BA |  |  |  | Package_LGA:LGA-8_3x5mm_P1.25mm | https://www.te.com/commerce/DocumentDelivery/DDEController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
U5,U7 | 2 | TPS5430DDA |  |  |  | Package_SO:TI_SO-PowerPAD-8_ThermalVias | http://www.ti.com/lit/ds/symlink/tps5430.pdf
U6 | 1 | TPD4S012DRYR |  |  |  | sky:PSON50P145X100X60-6N
U8 | 1 | MAX-M8C |  |  |  | RF_GPS:ublox_MAX | https://www.u-blox.com/sites/default/files/MAX-M8-FW3_DataSheet_%28UBX-15031506%29.pdf
U10 | 1 | W25Q128JVS |  |  |  | Package_SO:SOIC-8_5.3x5.3mm_P1.27mm | https://www.winbond.com/resource-files/w25q128jv_dtr%20revc%2003272018%20plus.pdf
Y1 | 1 | 8 MHz |  |  |  | Crystal:Crystal_SMD_3225-4Pin_3.2x2.5mm | ~

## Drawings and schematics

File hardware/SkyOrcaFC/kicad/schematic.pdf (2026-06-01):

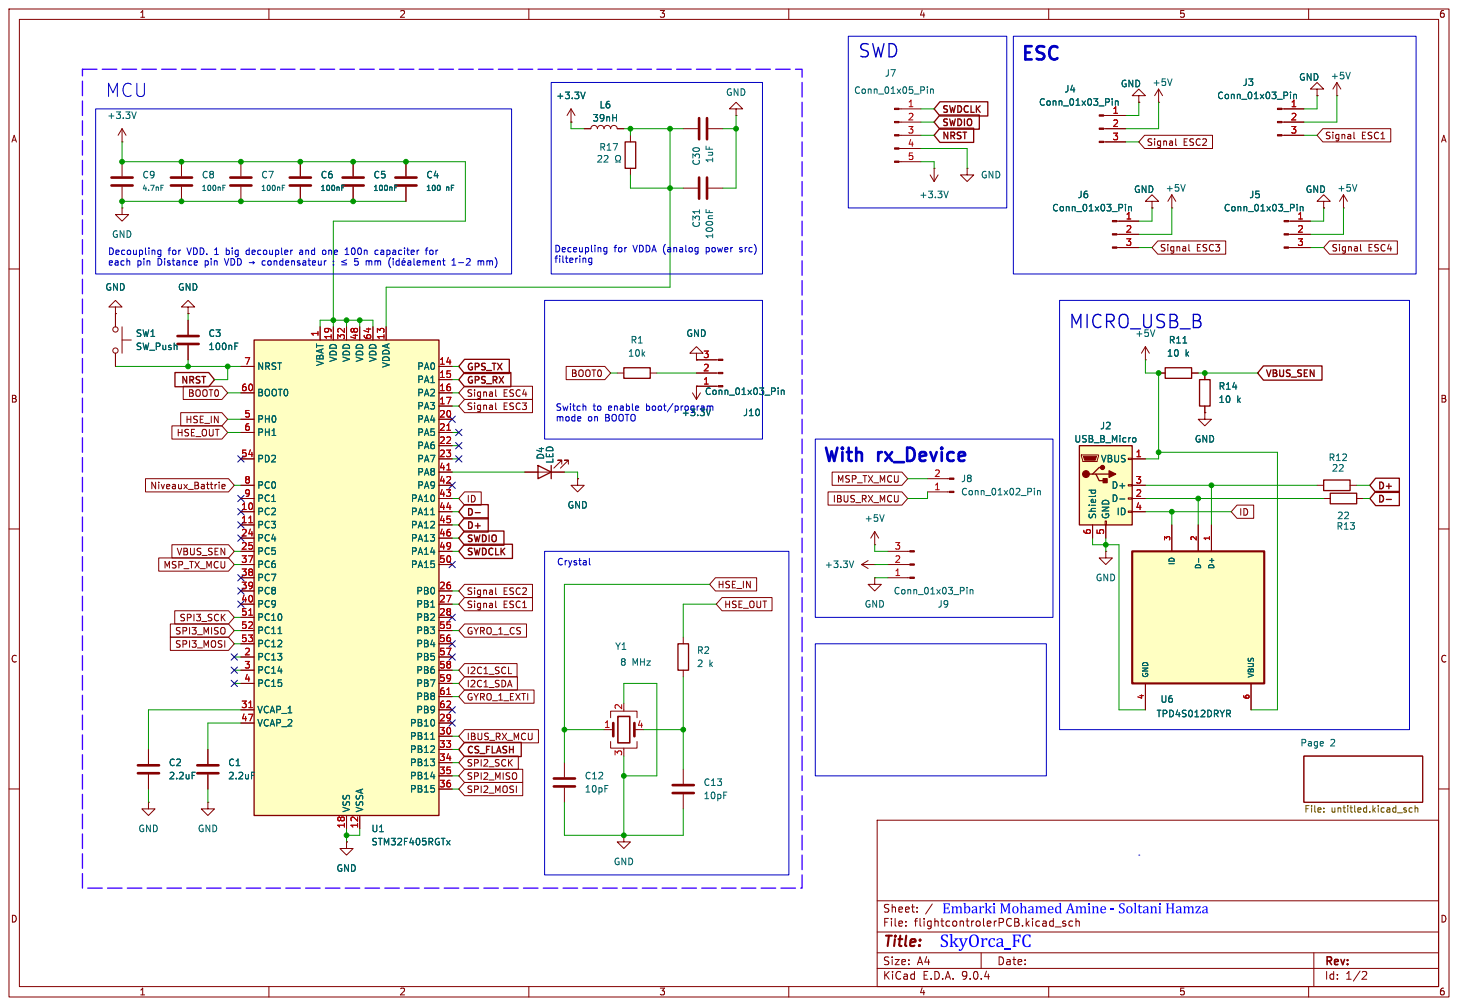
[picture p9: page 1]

1 VDD 19 VDD 32 VSS 18 VDD 48 VSSA 12 VDD 64 VDDA 13 PA0 14 PA1 15 PA2 16 PA3 17 PA4 20 PA5 21 PA6 22 PA7 23 PA8 41 PA9 42 PA10 43 PA11 44 PA12 45 PA13 46 PA14 49 PA15 50 PB0 26 PB1 27 PB2 28 PB3 55 PB4 56 PB5 57 PB6 58 PB7 59 PB8 61 PB9 62 PB10 29 PB11 30 PB12 33 PB13 34 PB14 35 PB15 36 U1STM32F405RGTx C13

1 VDD 19 VDD 32 VSS 18 VDD 48 VSSA 12 VDD 64 VDDA 13 PA0 14 PA1 15 PA2 16 PA3 17 PA4 20 PA5 21 PA6 22 PA7 23 PA8 41 PA9 42 PA10 43 PA11 44 PA12 45 PA13 46 PA14 49 PA15 50 PB0 26 PB1 27 PB2 28 PB3 55 PB4 56 PB5 57 PB6 58 PB7 59 PB8 61 PB9 62 PB10 29 PB11 30 PB12 33 PB13 34 PB14 35 PB15 36 D4 LED

Switch to enable boot/program
mode on BOOTO

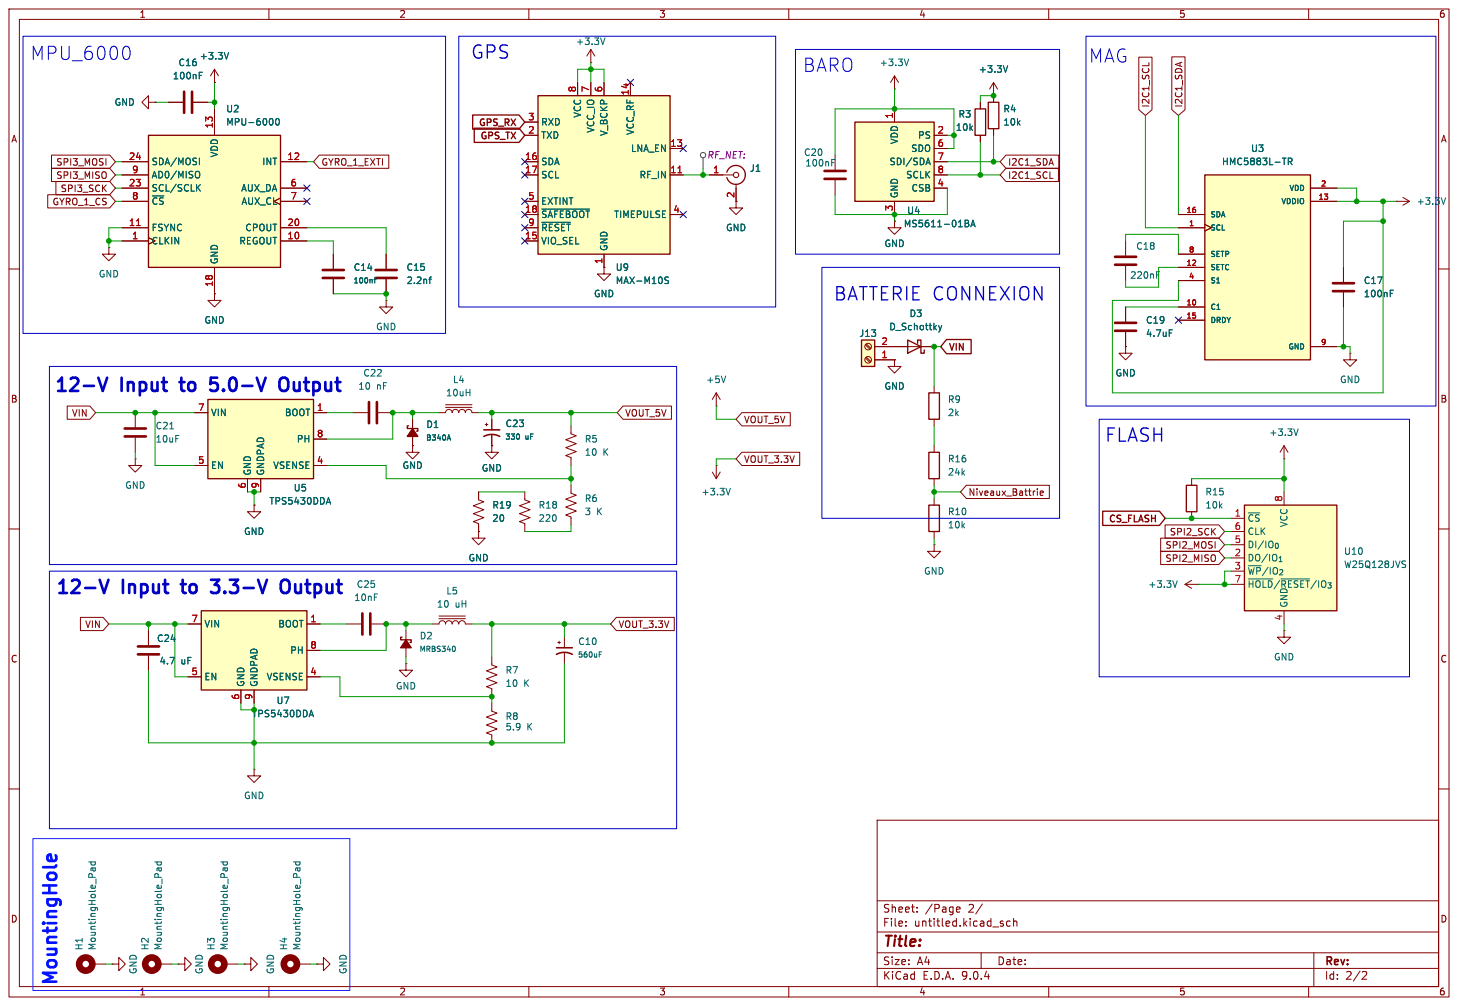
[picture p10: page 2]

1 GND
PS 2 SDO 6 SDI/SDA 7 SCLK 8 CSB 4 VDD

9 BOOT 1 PH 8 VSENSE 4 U5 TPS5430DDA GND GND

9 BOOT 1 PH 8 VSENSE 4 GND

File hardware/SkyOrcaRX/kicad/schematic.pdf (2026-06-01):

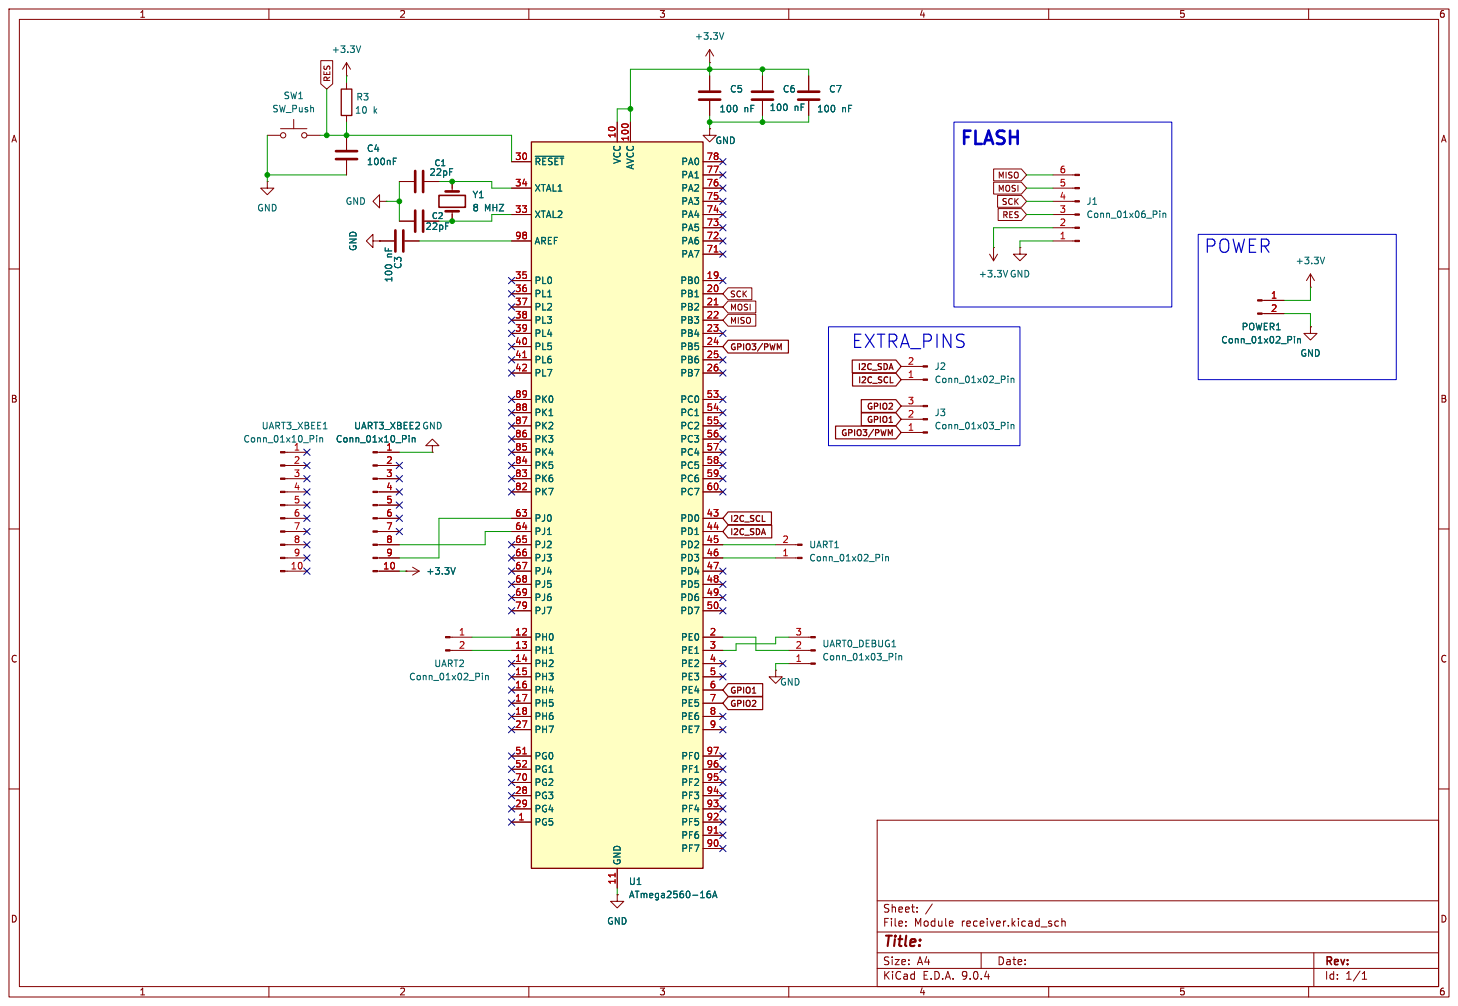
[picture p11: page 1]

Id: 1/1 Title: File: Module receiver.kicad_sch Sheet: /

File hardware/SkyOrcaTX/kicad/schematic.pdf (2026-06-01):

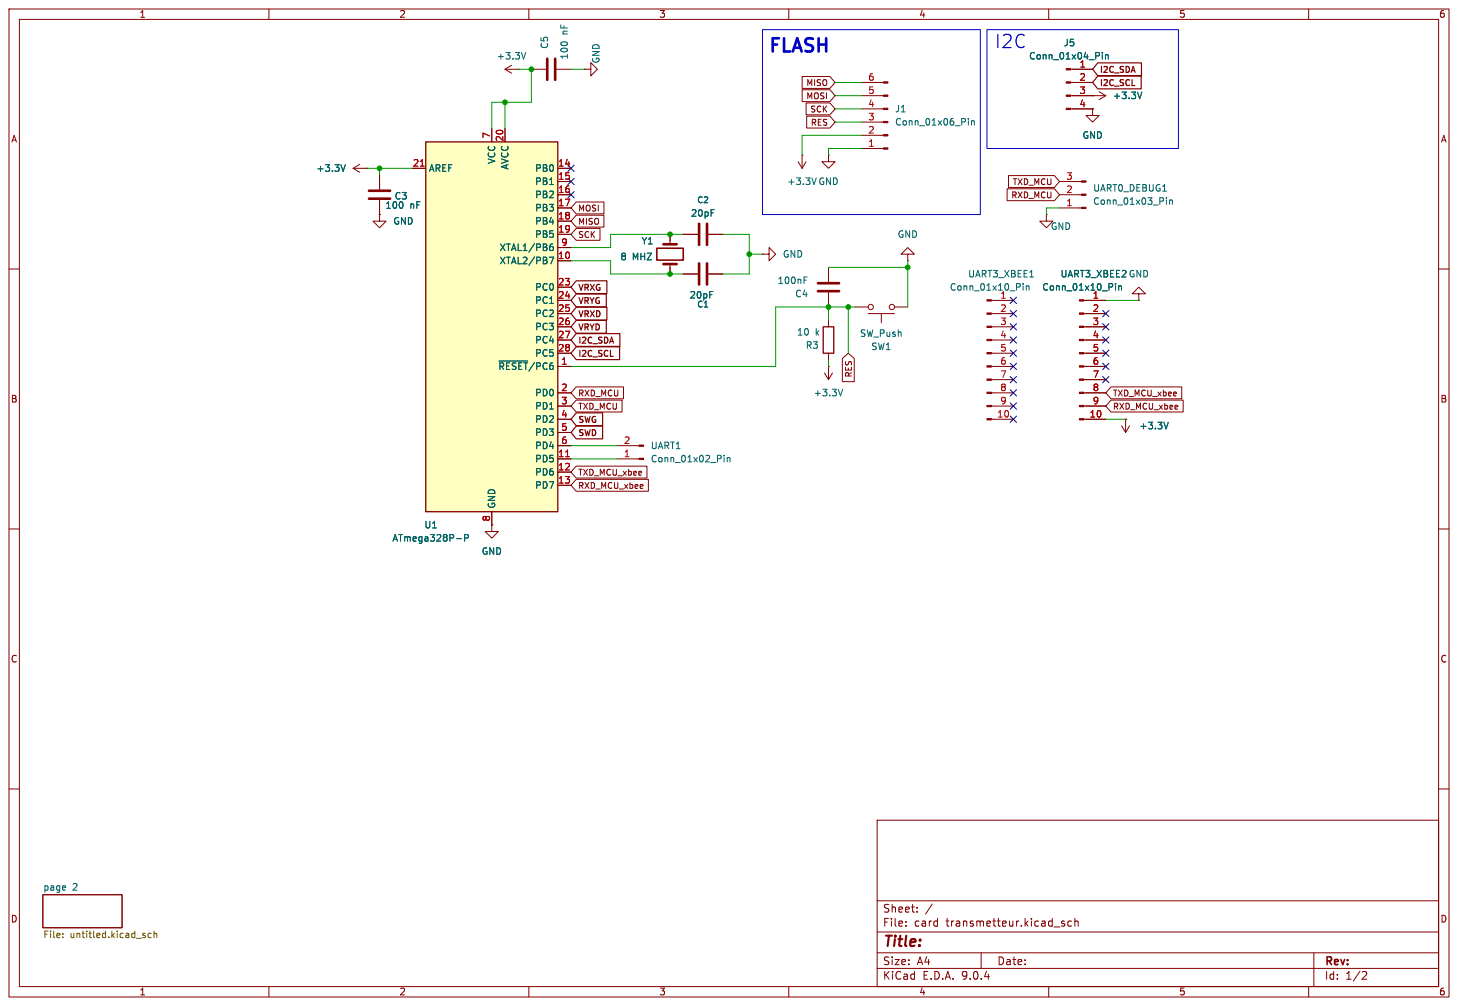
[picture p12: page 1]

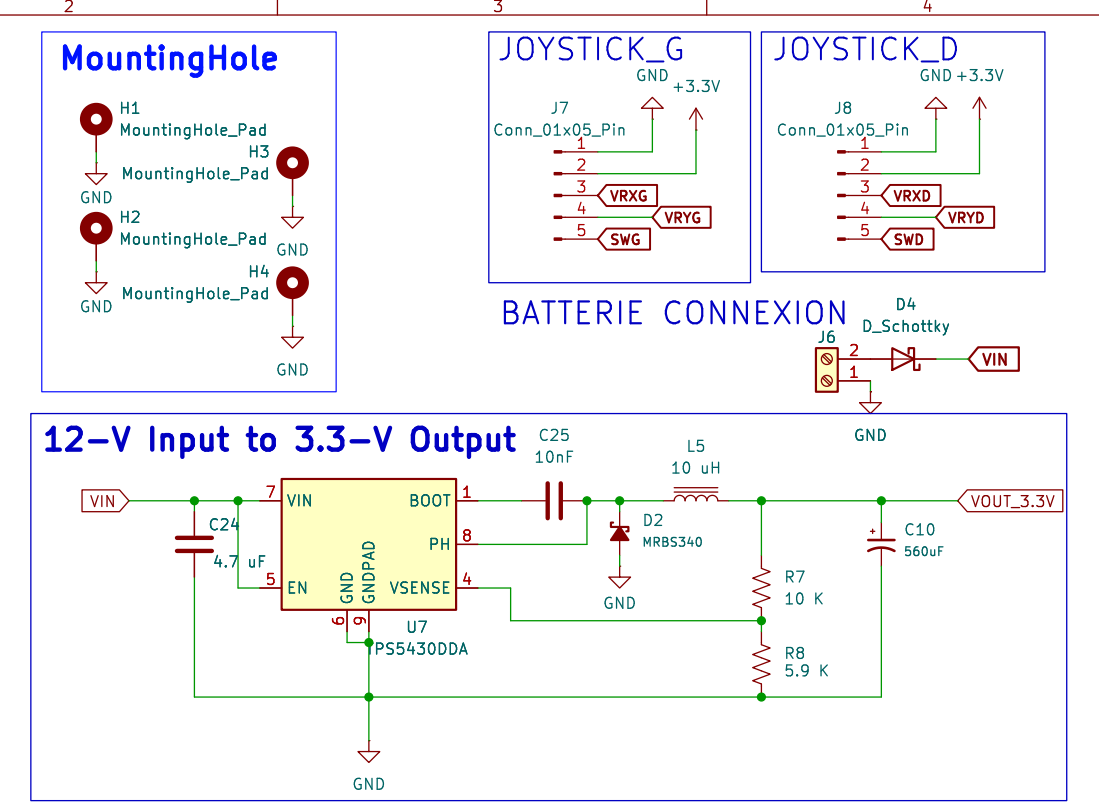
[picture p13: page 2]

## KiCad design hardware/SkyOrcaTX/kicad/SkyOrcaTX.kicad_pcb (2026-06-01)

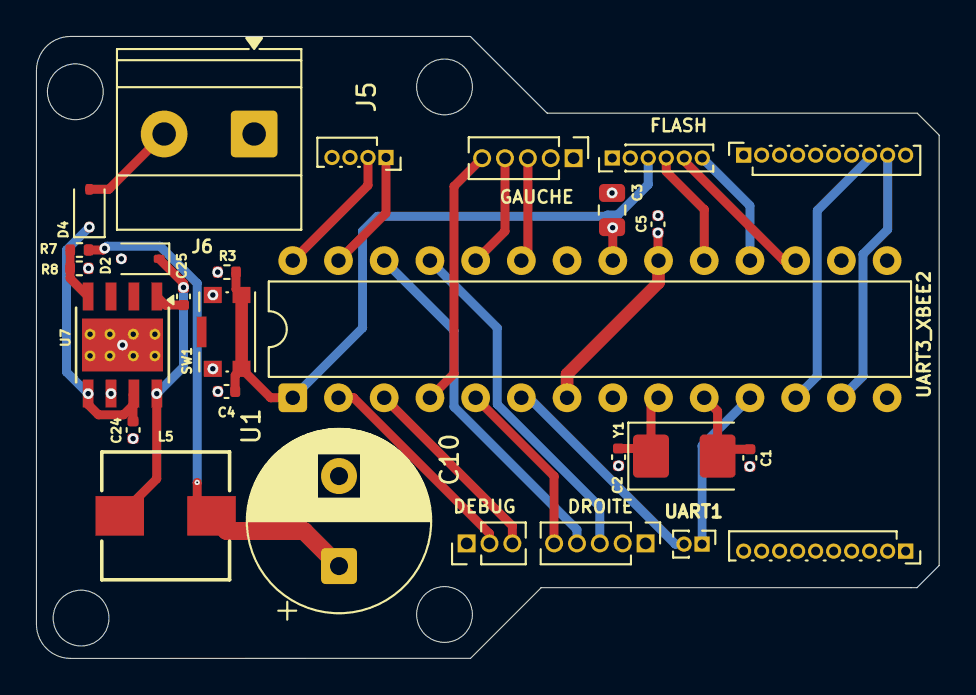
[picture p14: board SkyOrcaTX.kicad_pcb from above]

Board: 4 copper layers, 50.2 x 34.6 mm, 27 parts (0 on the bottom side), 28 nets.

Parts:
C1, C2: 20pF; C_0402_1005Metric
C3: 100 nF; C_0805_2012Metric
C4: 100nF; C_0402_1005Metric
C5: 100 nF; C_0402_1005Metric
C10: 560uF; CP_Radial_D10.0mm_P5.00mm
C24: 4.7 uF; C_0402_1005Metric
C25: 10nF; C_0402_1005Metric
D2: MRBS340; D_SOD-323
D4: D_Schottky; D_SOD-323
DEBUG: Conn_01x03_Pin; PinHeader_1x03_P1.27mm_Vertical
DROITE: Conn_01x05_Pin; PinHeader_1x05_P1.27mm_Vertical
FLASH: Conn_01x06_Pin; PinHeader_1x06_P1.00mm_Vertical
GAUCHE : Conn_01x05_Pin; PinHeader_1x05_P1.27mm_Vertical
J5: Conn_01x04_Pin; PinSocket_1x04_P1.00mm_Vertical
J6: Screw_Terminal_01x02; TerminalBlock_Phoenix_MKDS-1,5-2_1x02_P5.00mm_Horizontal
L5: 10 uH; WE-HCI_7040
R3: 10 k; R_0402_1005Metric
R7: 10 K; R_0402_1005Metric
R8: 5.9 K; R_0402_1005Metric
SW1: SW_Push; SW_Push_1P1T-SH_NO_CK_KMR2xxG
U1: ATmega328P-P; DIP-28_W7.62mm
U7: TPS5430DDA; TI_SO-PowerPAD-8_ThermalVias
UART1: Conn_01x02_Pin; PinHeader_1x02_P1.00mm_Vertical
UART3_XBEE1, UART3_XBEE2: Conn_01x10_Pin; PinSocket_1x10_P1.00mm_Vertical
Y1: 8 MHZ; Crystal_SMD_5032-2Pin_5.0x3.2mm

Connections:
+3.3V: C3.1, C5.1, DROITE.2, FLASH.2, GAUCHE.2, J5.3, R3.2, U1.7 (VCC), U1.20 (AVCC), U1.21 (AREF), UART3_XBEE2.10
GND: C1.1, C2.1, C3.2, C4.2, C5.2, C10.2, C24.2, D2.2 (A), DEBUG.1, DROITE.1, FLASH.1, GAUCHE.1, J5.4, J6.1, R8.2, SW1.1, U1.8 (GND), U1.22 (GND), U7.6 (GND), U7.9 (GNDPAD), UART3_XBEE2.1
I2C_SCL: J5.2, U1.28 (PC5)
I2C_SDA: J5.1, U1.27 (PC4)
MISO: FLASH.6, U1.18 (PB4)
MOSI: FLASH.5, U1.17 (PB3)
unnamed: C25.1, D2.1 (K), L5.1, U7.8 (PH)
unnamed: D4.2 (A), J6.2
unnamed: U1.6 (PD4), UART1.2
unnamed: U1.11 (PD5), UART1.1
unnamed: C2.2, U1.9 (XTAL1/PB6), Y1.1
unnamed: C1.2, U1.10 (XTAL2/PB7), Y1.2
unnamed: C25.2, U7.1 (BOOT)
unnamed: R7.1, R8.1, U7.4 (VSENSE)
RES: C4.1, FLASH.3, R3.1, SW1.2, U1.1 (~RESET/PC6)
RXD_MCU: DEBUG.2, U1.2 (PD0)
RXD_MCU_xbee: U1.13 (PD7), UART3_XBEE2.9
SCK: FLASH.4, U1.19 (PB5)
SWD: DROITE.5, U1.5 (PD3)
SWG: GAUCHE.5, U1.4 (PD2)
TXD_MCU: DEBUG.3, U1.3 (PD1)
TXD_MCU_xbee: U1.12 (PD6), UART3_XBEE2.8
VIN: C24.1, D4.1 (K), U7.5 (EN), U7.7 (VIN)
VOUT_3.3V: C10.1, L5.2, R7.2
VRXD: DROITE.3, U1.25 (PC2)
VRXG: GAUCHE.3, U1.23 (PC0)
VRYD: DROITE.4, U1.26 (PC3)
VRYG: GAUCHE.4, U1.24 (PC1)

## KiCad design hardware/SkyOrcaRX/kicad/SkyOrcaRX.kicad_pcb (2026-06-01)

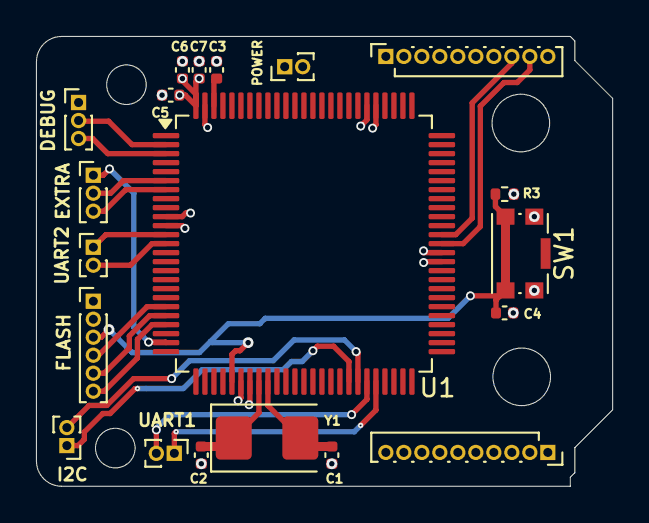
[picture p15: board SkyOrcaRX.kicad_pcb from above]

Board: 4 copper layers, 32.0 x 25.0 mm, 20 parts (0 on the bottom side), 22 nets.

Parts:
C1, C2: 22pF; C_0402_1005Metric
C3, C5, C6, C7: 100 nF; C_0402_1005Metric
C4: 100nF; C_0402_1005Metric
DEBUG: Conn_01x03_Pin; PinHeader_1x03_P1.00mm_Vertical
EXTRA: Conn_01x03_Pin; PinHeader_1x03_P1.00mm_Vertical
FLASH: Conn_01x06_Pin; PinHeader_1x06_P1.00mm_Vertical
I2C: Conn_01x02_Pin; PinHeader_1x02_P1.00mm_Vertical
POWER: Conn_01x02_Pin; PinHeader_1x02_P1.00mm_Vertical
R3: 10 k; R_0402_1005Metric
SW1: SW_Push; SW_Push_1P1T-SH_NO_CK_KMR2xxG
U1: ATmega2560-16A; TQFP-100_14x14mm_P0.5mm
UART1, UART2: Conn_01x02_Pin; PinHeader_1x02_P1.00mm_Vertical
UART3_XBEE1, UART3_XBEE2: Conn_01x10_Pin; PinSocket_1x10_P1.00mm_Vertical
Y1: 8 MHZ; Crystal_SMD_5032-2Pin_5.0x3.2mm

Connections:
+3.3V: C5.1, C6.1, C7.1, FLASH.2, POWER.1, R3.2, U1.10 (VCC), U1.31 (VCC), U1.61 (VCC), U1.80 (VCC), U1.100 (AVCC), UART3_XBEE2.10
GND: C1.1, C2.1, C3.2, C4.2, C5.2, C6.2, C7.2, DEBUG.1, FLASH.1, POWER.2, SW1.1, U1.11 (GND), U1.32 (GND), U1.62 (GND), U1.81 (GND), U1.99 (GND), UART3_XBEE2.1
GPIO1: EXTRA.2, U1.6 (PE4)
GPIO2: EXTRA.3, U1.7 (PE5)
GPIO3/PWM: EXTRA.1, U1.24 (PB5)
I2C_SCL: I2C.1, U1.43 (PD0)
I2C_SDA: I2C.2, U1.44 (PD1)
MISO: FLASH.6, U1.22 (PB3)
MOSI: FLASH.5, U1.21 (PB2)
unnamed: C3.1, U1.98 (AREF)
unnamed: U1.45 (PD2), UART1.2
unnamed: U1.46 (PD3), UART1.1
unnamed: DEBUG.2, U1.2 (PE0)
unnamed: DEBUG.3, U1.3 (PE1)
unnamed: U1.12 (PH0), UART2.1
unnamed: U1.13 (PH1), UART2.2
unnamed: U1.63 (PJ0), UART3_XBEE2.9
unnamed: U1.64 (PJ1), UART3_XBEE2.8
unnamed: C1.2, U1.34 (XTAL1), Y1.2
unnamed: C2.2, U1.33 (XTAL2), Y1.1
RES: C4.1, FLASH.3, R3.1, SW1.2, U1.30 (~RESET)
SCK: FLASH.4, U1.20 (PB1)

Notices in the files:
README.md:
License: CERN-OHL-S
